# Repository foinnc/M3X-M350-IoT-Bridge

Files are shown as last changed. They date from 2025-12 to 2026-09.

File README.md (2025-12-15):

# 🌉 M3X-M350-IoT-Bridge

**An Open Source IoT Expansion Box designed exclusively for the M350 CNC Controller.**

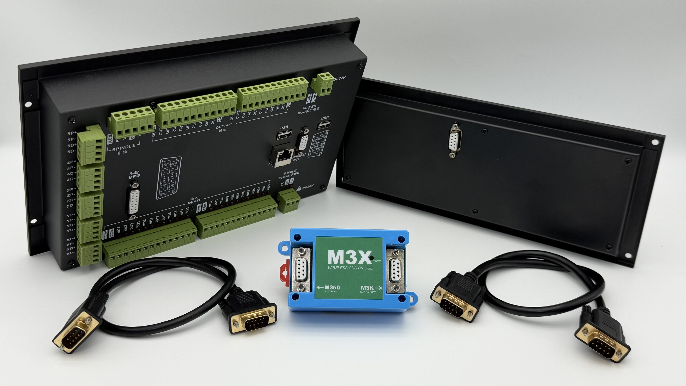
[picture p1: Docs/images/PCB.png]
M3X PCB
 
---

## ✨ 1. Project Overview: Unleash Wireless Imagination

The **M3X-M350-IoT-Bridge** is an open-source hardware project designed to empower the classic M350 CNC controller with modern **IoT (Internet of Things)** capabilities.

By integrating powerful **Wi-Fi** and **Bluetooth** wireless protocols, the M3X box acts as a bridge, allowing various Human-Machine Interfaces (HMI) and wireless terminals to access the M350 system.

**With the M3X, your M350 gains:**
* **Wireless Freedom:** Replace wired limitations with Wi-Fi/Bluetooth control.
* **Smart Connectivity:** Supports standard wireless protocols for flexible development.
* **Expanded Potential:** From simple remote jogging to complex cloud monitoring, unleash the wireless imagination of your CNC system.

### 📷 Product Visualization

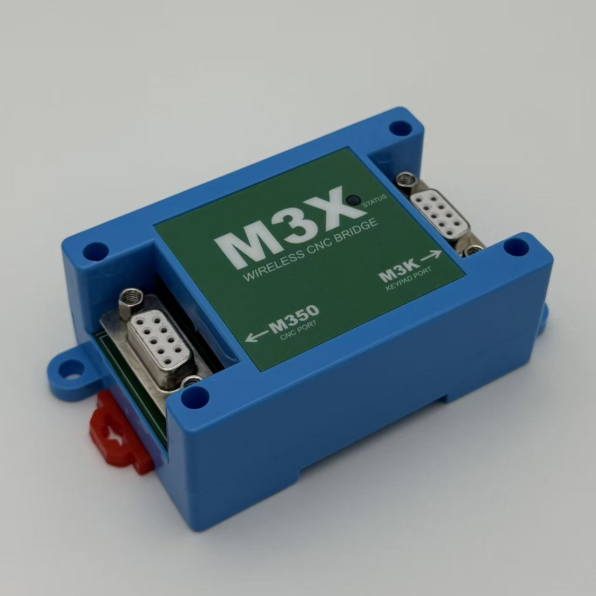
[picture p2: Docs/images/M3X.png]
M3X Project Banner
 

*(Note: The M3X is compact, robust, and designed to sit neatly beside your controller.)*

---

## 🔌 2. Connectivity & Power

We designed the M3X for ultimate simplicity. **Zero soldering, Zero complex wiring.**

* **Connection Method:** Connects via a single **DB9 Male-to-Male Extension Cable**.
* **Plug and Play:** Simply plug one end into the M3X and the other into the M350's serial port.
* **Power Supply:** No external power adapter is needed! The M3X draws 5V power directly from the M350 controller through the DB9 cable.

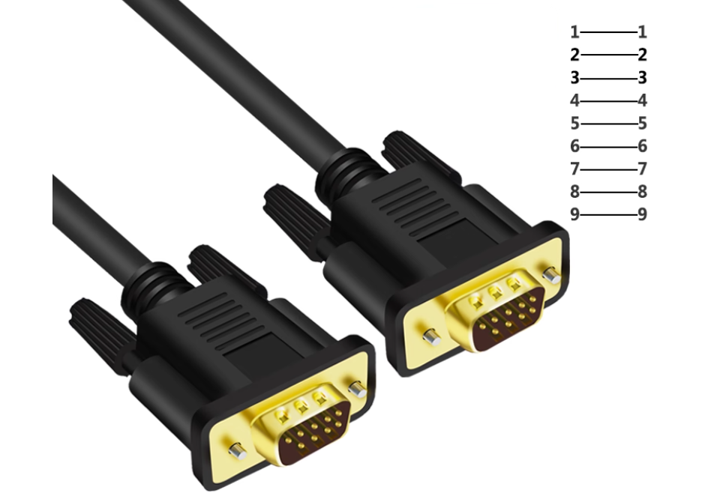
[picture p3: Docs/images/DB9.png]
DB9 Connection Cable
 

---

## 💻 3. Hardware Compatibility

The M3X is compatible with the majority of M350 controllers in the market:

| Hardware Version | Compatibility Status | Note |
| :--- | :--- | :--- |
| **M350 V2** | ✅ **Fully Compatible** | All V2 hardware versions support direct power and data. |
| **M350 V1** | ⚠️ **Partial Support** | Only V1 versions equipped with a **5V output** on the serial port are supported. |

---

## 📱 4. Application Case: Wi-Fi Web Control

The M3X allows you to control the CNC remotely via a web interface.

> **📢 Prerequisite (Important):**
> Before attempting to communicate with the M350, you must flash the firmware into the IoT Box.
>
> Please follow the [**Firmware Flashing Guide**](Docs/Flashing_Guide.md) to flash the `M3X_Web_Control_v1.0.bin` file to your device first.

### How to Use:

1.  **Power On:** Turn on your M350 (and thus the M3X).
2.  **Connect Wi-Fi:** On your Phone, Tablet (iPad/Android), or Laptop, search for the Wi-Fi hotspot.
    * **SSID (Name):** `M3X`
3.  **Open Browser:** Launch any web browser (Chrome, Safari, Edge, etc.) and enter the address:
    * **URL:** `192.168.4.1`

**You now have a wireless CNC control panel right in your hand!**

---

## ⚙️ 5. M350 System Configuration (Critical Setup)

### ⚠️ **CNC Firmware Requirement**
For the M3X to function correctly, your **M350 CNC Controller firmware** must be version **2025-12-11-00 or newer**. Earlier versions may not support the required Modbus communication protocol settings.

**➡️ M350 Firmware Download Link:** [https://github.com/foinnc/M350/releases/](https://github.com/foinnc/M350/releases/) 

---

For the M3X to communicate successfully, you **must** configure the M350 CNC Controller's internal parameters as follows.

**Go to the M350 "Parameters" page and set:**

| Parameter No. | Parameter Name | Setting Value | Description |
| :--- | :---: | :---: | :--- |
| **P279** | **Modbus RTU** | **Slave** | Sets M350 as a Modbus Slave (Server). |
| **P267** | **Serial 2 Baud Rate** | **115200** | Matches the M3X high-speed communication rate. |
| **P296** | **Parity Check** | **Default** | Leave as system default (Usually None/Even). |
| **P297** | **Stop Bits** | **Default** | Leave as system default (Usually 1 bit). |

> ⚠️ **IMPORTANT:** After changing these parameters, you **MUST REBOOT (Restart)** the M350 controller for the changes to take effect.

---

## 🎬 6. Demos & Gallery

See the M3X in action!

### Video Demonstration
[**▶️ Click here to watch the M3X Setup & Demo Video**](https://youtu.be/5DFLAazw6eI)

*(Or use the thumbnail embed method below)*
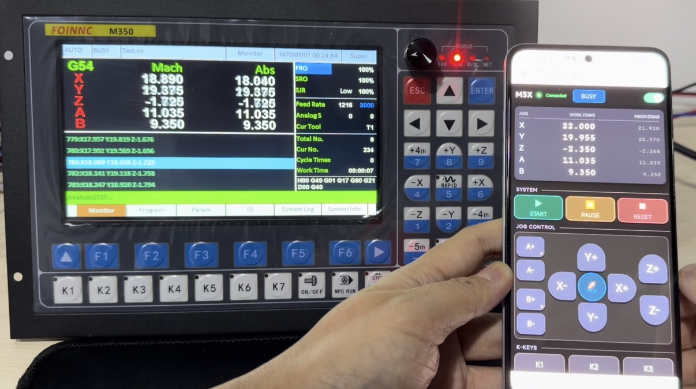
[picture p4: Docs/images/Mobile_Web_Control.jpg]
Video Thumbnail


### Project Gallery
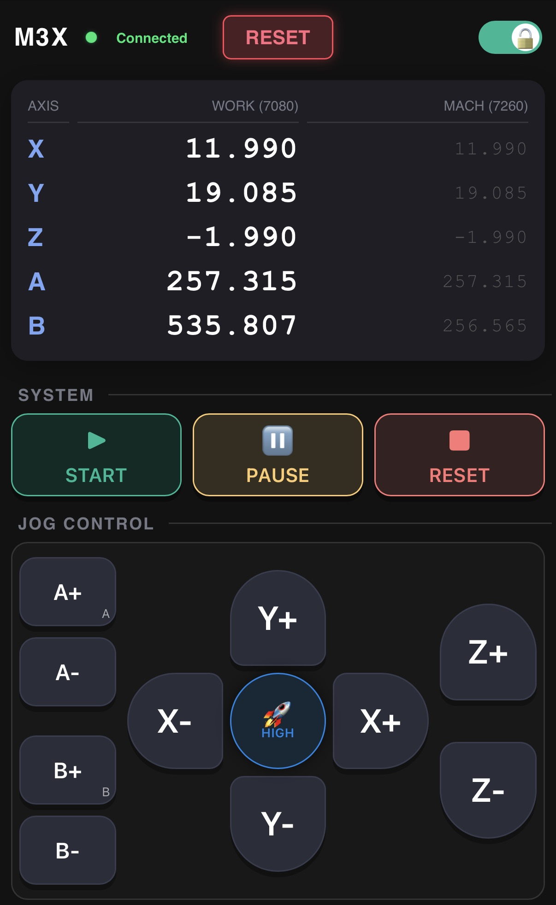
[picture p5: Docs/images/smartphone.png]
Web Control Interface

*(Caption: The responsive web interface on a smartphone)*

M3X Installed
*(Caption: The M3X bridge connected to the M350 CNC controller)*

---

## 📚 Documentation & Resources

* **Flash Firmware:** [Firmware Flashing Guide](Docs/Flashing_Guide.md) - Step-by-step flashing instructions.
* **Hardware Details:** [ESP32-C3 Core Module Introduction](Docs/ESP32_C3_Core_Introduction.md) - Pinouts and specs. 
  > **💡 Note:** The core component, the **ESP32-C3 Super Mini**, can be purchased as a readily available module, eliminating the need for custom PCB design. 
* **Source Code:** Check the `Firmware/` folder for source code examples.
* **Schematics:** Check the `Hardware/` folder for circuit diagrams.

---

_Open Source Project - Use at your own risk and enjoy the freedom of DIY!_

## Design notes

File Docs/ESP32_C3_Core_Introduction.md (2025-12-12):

# ⚡ ESP32-C3 Core Module Introduction

This document provides a detailed overview of the ESP32-C3 core module, including its technical specifications, hardware resources, and critical operating instructions.

---

## ⚙️ 1. Product Specifications

The core module is built around the highly integrated ESP32-C3 chip, offering robust Wi-Fi and Bluetooth capabilities in a compact design.

| Feature | Specification |
| :--- | :--- |
| **Processor** | ESP32-C3, 32-bit RISC-V Single-Core CPU |
| **Frequency** | Up to 160 MHz |
| **Wi-Fi** | 802.11 b/g/n, 2.4 GHz (Station, SoftAP, SoftAP+Station, Promiscuous) |
| **Bluetooth** | Bluetooth 5.0 (BLE) |
| **Low Power** | Deep-sleep current approx. 43 $\mu$A |
| **Memory** | 400 KB SRAM, 384 KB ROM, Built-in 4 MB Flash |
| **Chip Model** | ESP32C3FN4 |
| **Size** | 23 $\times$ 19 mm classic form factor |
| **Design** | Single-sided components, Surface Mount Design (SMD) |
| **Onboard Blue LED** | Connected to **GPIO8** |

---

## 🔌 2. Rich Peripheral Interfaces

The module provides a rich set of I/O and communication interfaces:

* **General Purpose I/O (GPIO):** 11x (PWM capable)
* **Analog Input:** 4x ADC (Analog-to-Digital Converter)
* **Serial Communication:** 2x UART
* **Synchronous Communication:** 1x I2C, 1x SPI

### 2.1 Pinout Diagram

The following diagram illustrates the pin assignment and peripheral mapping for the core module:

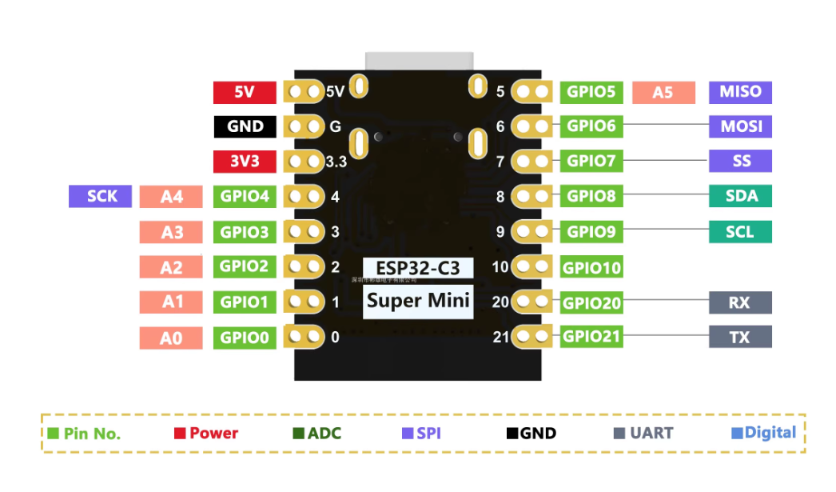
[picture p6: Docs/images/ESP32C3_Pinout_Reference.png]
ESP32-C3 Core Module Pinout Diagram
 

---

## ⚠️ 3. Operational Notes and Instructions

### 3.1 External Power Supply

* If external power is required, connect the **Positive (+)** terminal of the external supply to the **5V** pin, and the **Ground (GND)** terminal to the negative pole.
* **Supported Range:** The module supports a voltage range of **3.3V to 6V**.
* **Crucial Warning:** When connecting an external power supply, **USB power must be disconnected**. USB and external power are mutually exclusive; use only one source to prevent damage.

### 3.2 Entering Download Mode (Flashing)

The chip must be manually set to Download Mode before flashing new firmware (required for each new connection/flashing session).

1.  **Press and Hold** the **BOOT** button on the ESP32-C3 module.
2.  **Press** the **RESET** button.
3.  **Release** the **RESET** button.
4.  **Finally, Release** the **BOOT** button.

The ESP32-C3 should now be in Download Mode. If the port disconnects unexpectedly (sometimes indicated by a port recognition sound), you may need to repeat the sequence.

---

## 💡 4. Schematic Diagram (原理图)

For hardware replication, debugging, and detailed component inspection, please refer to the schematic diagram.

The full schematic is provided in the repository's documentation files:

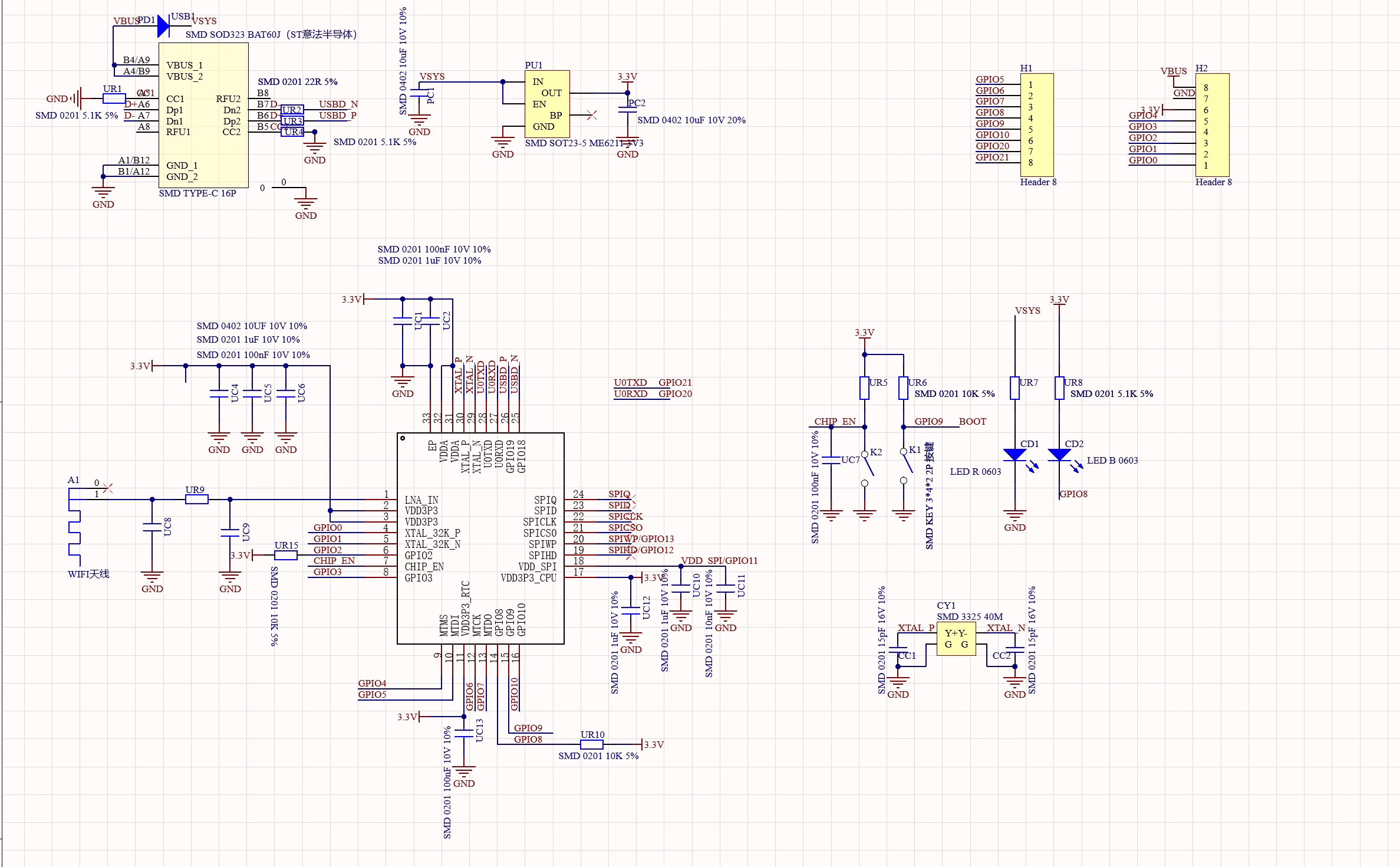
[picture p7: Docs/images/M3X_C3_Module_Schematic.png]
M3X Core Module Schematic Preview


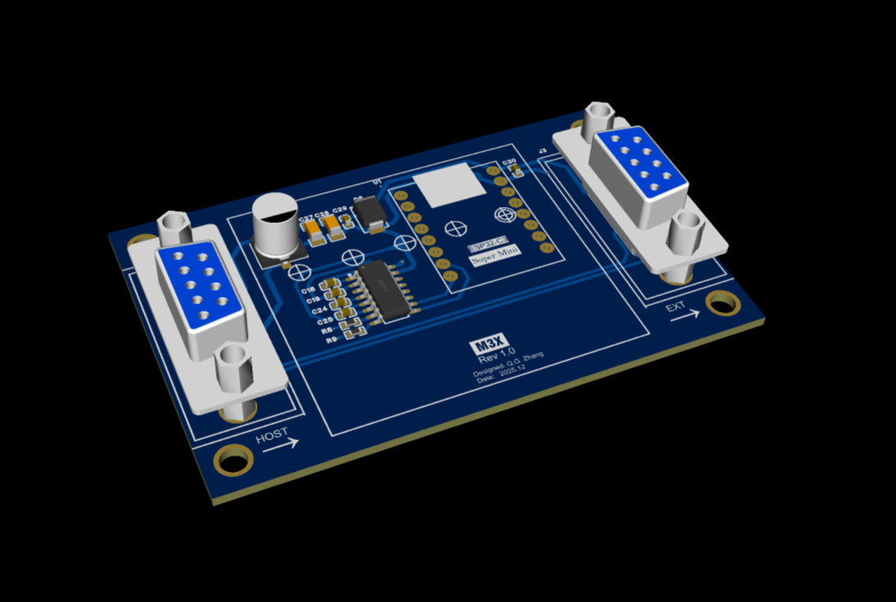
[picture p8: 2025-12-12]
Hardware/PCB_Gerber/3D.png

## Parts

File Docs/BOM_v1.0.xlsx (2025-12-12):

No. | Quantity | Comment | Designator | Footprint | Value | Manufacturer Part | Manufacturer | Supplier Part | Supplier
1 | 6 | 100nF | C18,C19,C24,C25,C29,C30 | C0603 | 100nF | CC0603KRX7R9BB104 | YAGEO(国巨) | C14663 | LCSC
2 | 2 | 22uF | C26,C27 | C1206 | 22uF | CL31A226KPHNNNE | SAMSUNG(三星) | C5672 | LCSC
3 | 1 | 100uF | C28 | CAP-SMD_BD6.3-L6.6-W6.6-LS7.2-FD | 100uF | RVT1C101M0605 | HONOR(荣誉) | C37308 | LCSC
4 | 1 | SMBJ6.5A | D6 | SMB_L4.6-W3.6-LS5.3-RD |  | SMBJ6.5A | MDD(辰达半导体) | C113978 | LCSC
5 | 2 | DS1034-09FUNSi44 | J2,J3 | DSUB-TH_2-5747706-0 |  | DS1034-09FUNSi44 | CONNFLY | C77831 | LCSC
6 | 2 | 20Ω | R8,R9 | R0603 | 20Ω | 0603WAF200JT5E | UNI-ROYAL(厚声) | C22950 | LCSC
7 | 1 | ESP32_C3mini | U1 | ESP32_C3_mini
8 | 1 | MAX232ACSE | U4 | SOP-16_L10.0-W3.9-P1.27-LS6.0-BL

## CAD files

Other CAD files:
Hardware/Case_Drawings/1152(3-59-2).dwg

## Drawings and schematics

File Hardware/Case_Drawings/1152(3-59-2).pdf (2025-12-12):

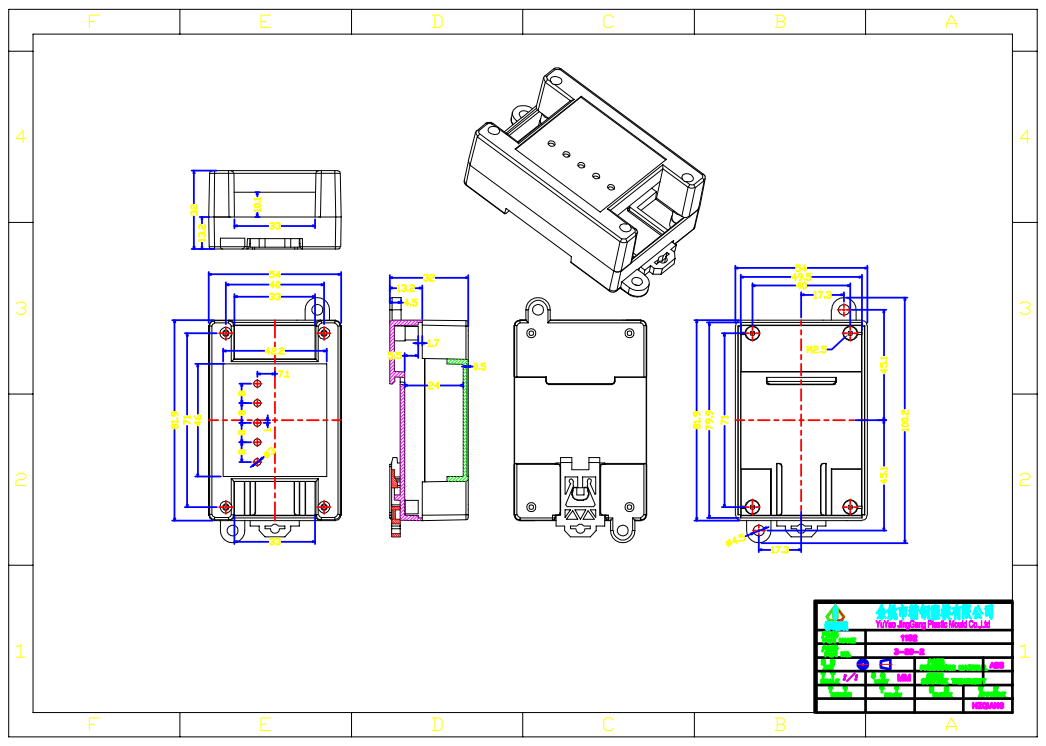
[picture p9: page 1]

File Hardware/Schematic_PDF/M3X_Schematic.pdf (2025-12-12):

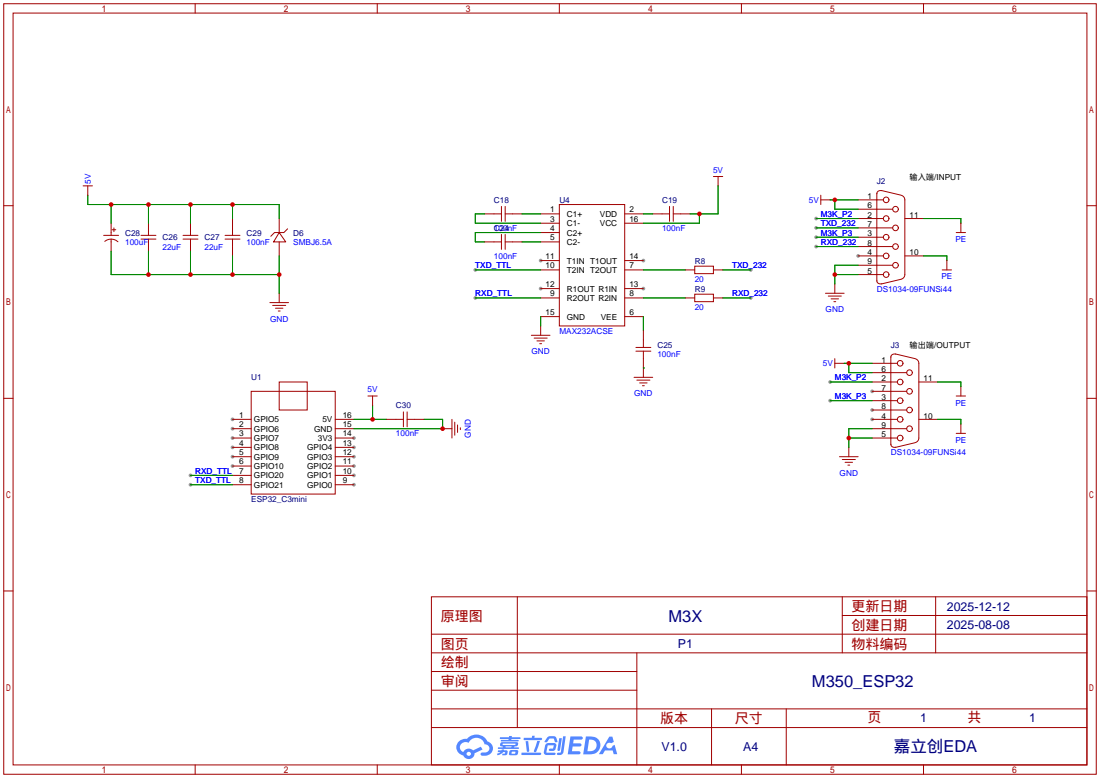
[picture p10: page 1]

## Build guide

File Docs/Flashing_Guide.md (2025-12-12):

# 💻 ESP32-C3 Firmware Flashing Guide (Beginner's Edition)

This guide provides **step-by-step instructions** for flashing the M3X control firmware onto your ESP32-C3 core module using the simple, browser-based **Adafruit WebSerial ESPTool**.

---

## ⚙️ 1. Preparation Checklist

Ensure you have all the necessary components and files before proceeding:

1.  **Core Module:** An **ESP32-C3 Super Mini** core board.
2.  **Cable:** A reliable USB Type-C data cable.
3.  **Firmware File:** The specific `.bin` file you need to flash.
    * **File Location in this Repository:** `Firmware\01_Web_Touch_Console\M3X_Web_Control_v1.0.bin`
    * **Function:** This firmware allows you to control the M350 via a web interface or mobile phone using the core board's Wi-Fi hotspot.
4.  **Browser Tool:** The online flashing tool.
    * **Tool URL:** [https://adafruit.github.io/Adafruit_WebSerial_ESPTool/](https://adafruit.github.io/Adafruit_WebSerial_ESPTool/)
    * **Requirement:** Use a Chromium-based browser (Google Chrome or Microsoft Edge).

---

## ⚠️ 2. Essential Setup: Enter Download Mode

Before your computer can communicate with the ESP32-C3 for flashing, the module must be placed into a special **Download Mode** (also called Bootloader Mode).

### Procedure:

1.  **Connect the Cable:** Plug the USB Type-C cable into the module and your computer.
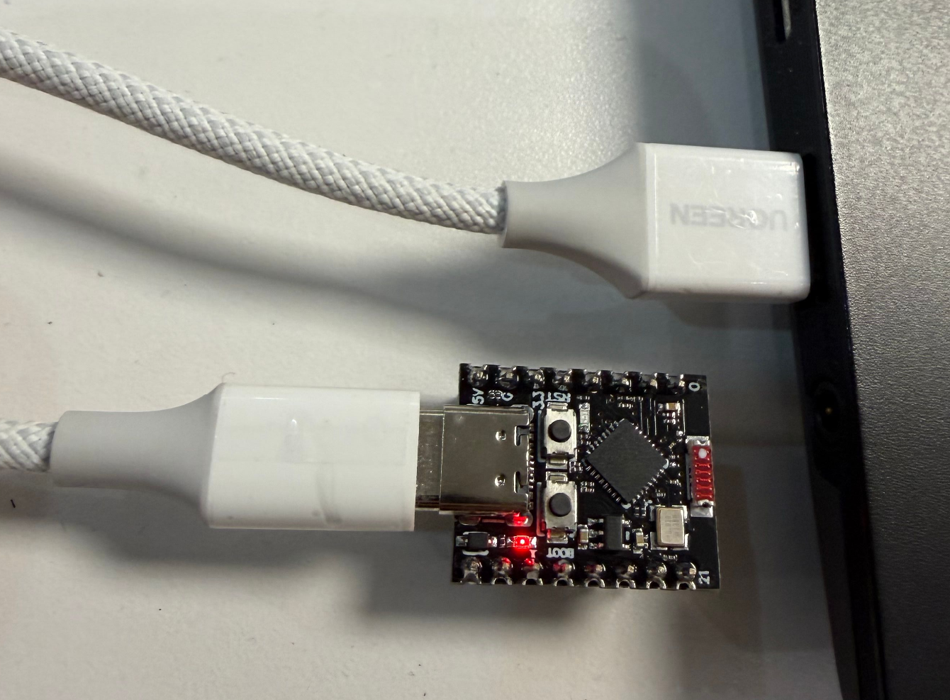
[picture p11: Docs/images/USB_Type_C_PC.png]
USB_Type_C_PC
 

2.  **Locate Buttons:** Identify the **BOOT** button (usually near the USB port) and the **RESET** button.
3.  **Press BOOT:** **Press and HOLD DOWN** the **BOOT** button (Do not release yet!).
4.  **Press RESET:** While holding BOOT, briefly **PRESS and RELEASE** the **RESET** button.
5.  **Release BOOT:** Wait for about one second, then **RELEASE** the **BOOT** button.

> **Crucial Note:** This manual procedure is required **every time** you start the flashing process. If you encounter errors later, repeat these steps immediately before reconnecting.

---

## 🚀 3. Step-by-Step Flashing Procedure

Follow these steps precisely to successfully burn the firmware:

### Step A: Set Baud Rate and Connect the Device

1.  Open the **Adafruit WebSerial ESPTool** URL in your browser: [https://adafruit.github.io/Adafruit_WebSerial_ESPTool/](https://adafruit.github.io/Adafruit_WebSerial_ESPTool/)
2.  **Set Baud Rate:** Locate the baud rate selection dropdown menu (usually near the top right corner). **Select `115200`**.
    > **Note on Baud Rate:** While the tool might support faster rates, **115200** is the standard, most reliable rate for the initial connection and stability across different computer systems.
3.  Locate the large **CONNECT** button (usually blue) on the page and click it.
4.  A pop-up window will appear, listing available serial ports.
5.  **Select Port:** Choose the port that corresponds to your ESP32-C3 (e.g., 'USB to UART').
6.  **Confirm Connection:** Click **Connect**. The button should change to **DISCONNECT** if successful.
    * *(If the tool fails to connect, ensure the module is in Download Mode (Section 2.1).)*

### Step B: Load the Firmware File

1.  After connecting, look for the **"Files to flash"** section on the page.
2.  **Set Start Address:** Ensure the address field is set to **`0x0`** (zero).
    * **Start Address Value:** `0`
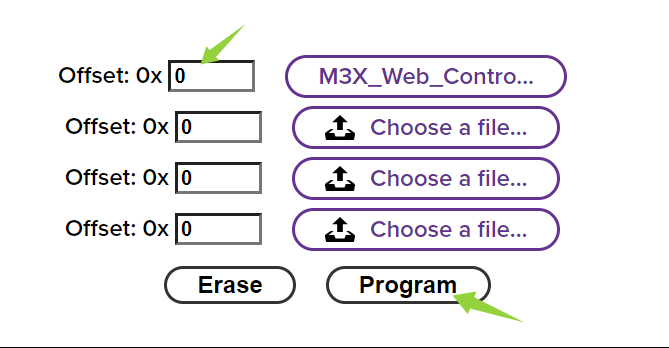
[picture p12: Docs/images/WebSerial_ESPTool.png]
 
    
3.  **Select File:** Click the **Browse** button next to the address field.
4.  A file explorer window will open. Navigate to the firmware file **`M3X_Web_Control_v1.0.bin`** in your local clone of the repository.

### Step C: Execute Flashing

1.  Once the file is selected and the address is confirmed, click the **Program** button.
2.  **Monitor Progress:** The tool will automatically start erasing the old firmware and writing the new `.bin` file. Watch the progress bar in the log window.
3.  **Wait for Success:** The process is complete when you see a bright green **"Success!"** message in the log area. **Do not disconnect the cable until this message appears.**

### Step D: Disconnect and Run

1.  Click the **DISCONNECT** button on the web tool interface.
2.  **Run Firmware:** Briefly press the **RESET** button on the ESP32-C3 core board.

The module will exit Download Mode and immediately begin running the new `M3X_Web_Control_v1.0.bin` firmware. Your core module is now ready to broadcast its Wi-Fi hotspot for M350 control.

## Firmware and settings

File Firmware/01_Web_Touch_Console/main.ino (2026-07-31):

#include <WiFi.h>
#include <WebServer.h>
#include <WebSocketsServer.h>
// *** 必须先安装 ModbusMaster 库 (D. G. Lunn 版本) ***
#include <ModbusMaster.h> 

// --- 指示灯定义 ---
#define LED_PIN 8  // GPIO8，低电平点亮

const char* ssid = "M3X";
const char* password = "12345678";

// --- 硬件定义 ---
const int RXD1 = 20;
const int TXD1 = 21;

// --- Modbus 设置 ---
const uint8_t SLAVE_ID = 0x01; 
const uint16_t START_REG_WRITE = 6908; 
const uint16_t REG_READ_WORK = 7080; 
const uint16_t REG_READ_MACH = 7260; 
const uint16_t REG_READ_STAT = 10002; 

ModbusMaster node; 
unsigned long lastReadTime = 0;
const long readInterval = 100; 

WebServer server(80);
WebSocketsServer webSocket = WebSocketsServer(81); 

// LED 状态变量
bool led_state = false; 

// 闪烁 LED 函数
void blinkLED() {
    led_state = !led_state;
    digitalWrite(LED_PIN, led_state ? LOW : HIGH);
}

// *********************************************************************************
// ********* HTML 界面 (保持不变) *********
// *********************************************************************************
const char MAIN_page[] PROGMEM = R"HTML(
<!DOCTYPE html>
<html>
<head>
<meta charset="UTF-8">
<meta name="viewport" content="width=device-width, initial-scale=1, user-scalable=no, maximum-scale=1, user-scalable=0">
<title>M3X 5-Axis Pro</title>
<style>
* { box-sizing: border-box; }
:root {
    --bg-color: #121212; --card-bg: #1e1e24; --btn-bg: #2a2d3a; --btn-border: #383c4d;
    --text-main: #ffffff; --text-sub: #757985; --text-accent: #7aa5f5;
    --btn-start: #00b894; --btn-pause: #fdcb6e; --btn-reset: #ff7675; 
    --btn-speed: #0984e3; --btn-fkey:  #6c5ce7; 
}
body { 
    font-family: 'Roboto', sans-serif; background-color: var(--bg-color); color: var(--text-main);
    margin: 0; padding: 8px; display: flex; flex-direction: column; align-items: center;
    min-height: 100vh; touch-action: manipulation; -webkit-user-select: none; user-select: none;
}
@keyframes breathing {
    0% { box-shadow: 0 0 2px rgba(0, 230, 118, 0.3); transform: scale(1); }
    50% { box-shadow: 0 0 8px rgba(0, 230, 118, 0.8); transform: scale(1.2); }
    100% { box-shadow: 0 0 2px rgba(0, 230, 118, 0.3); transform: scale(1); }
}
.header-panel {
    width: 100%; max-width: 450px; display: grid; 
    grid-template-columns: 1fr auto 1fr; 
    align-items: center; gap: 5px; margin-bottom: 10px; padding: 5px 2px;
}
.left-group { display: flex; align-items: center; gap: 12px; justify-self: start; }
h2 { margin: 0; font-size: 18px; font-weight: 900; color: var(--text-main); letter-spacing: 1px; line-height: 1; }
.conn-wrapper { display: flex; align-items: center; gap: 6px; }
.dot { width: 8px; height: 8px; border-radius: 50%; background: #555; transition: all 0.3s; }
.dot.ok { background: #00e676; animation: breathing 2s infinite ease-in-out; } 
#conn-text { font-size: 10px; color: #666; font-weight: bold; padding-top: 1px;}
.sys-status {
    justify-self: center; font-size: 14px; font-weight: bold;
    color: #fff; background: #333; padding: 6px 12px; border-radius: 6px;
    min-width: 80px; text-align: center; white-space: nowrap;
    border: 1px solid #444; transition: all 0.3s;
}
.st-idle { background-color: rgba(0, 184, 148, 0.2); color: #00b894; border-color: #00b894; }
.st-run  { background-color: rgba(9, 132, 227, 0.2); color: #74b9ff; border-color: #0984e3; }
.st-reset { background-color: rgba(255, 71, 87, 0.25); color: #ff6b81; border-color: #ff4757; box-shadow: 0 0 8px rgba(255, 71, 87, 0.4); }
.st-off  { background-color: #2d3436; color: #636e72; border-color: #636e72; }
.lock-wrapper { justify-self: end; display: flex; align-items: center; }
.switch { position: relative; display: inline-block; width: 46px; height: 24px; }
.switch input { opacity: 0; width: 0; height: 0; }
.slider { position: absolute; cursor: pointer; top: 0; left: 0; right: 0; bottom: 0; background-color: #444; transition: .4s; border-radius: 34px; border: 1px solid #666; }
.slider:before { position: absolute; content: "🔒"; font-size: 12px; display:flex; justify-content:center; align-items:center; height: 20px; width: 20px; left: 1px; bottom: 1px; background-color: #bbb; transition: .4s; border-radius: 50%; color: #333;}
input:checked + .slider { background-color: var(--btn-start); border-color: var(--btn-start); }
input:checked + .slider:before { transform: translateX(22px); content: "🔓"; background-color: #fff; }
.ui-disabled { opacity: 0.3; pointer-events: none; filter: grayscale(0.8); transition: opacity 0.3s; }
.dro-panel {
    background-color: var(--card-bg); border-radius: 12px; padding: 12px; width: 100%; max-width: 450px;
    box-shadow: 0 4px 20px rgba(0,0,0,0.3); display: grid; grid-template-columns: 30px 1fr 1fr; gap: 6px;
    align-items: center; margin-bottom: 5px;
}
.dro-header { color: var(--text-sub); font-size: 10px; text-align: right; padding-bottom: 5px; border-bottom: 1px solid rgba(255,255,255,0.1); }
.axis-name { font-size: 18px; font-weight: 900; color: var(--text-accent); }
.coord-val { font-family: 'Courier New', monospace; text-align: right; letter-spacing: 0.5px; }
.work-pos { font-size: 22px; font-weight: bold; color: var(--text-main); }
.mach-pos { font-size: 14px; color: #555; }
.controls-wrapper { width: 100%; max-width: 450px; display: flex; flex-direction: column; }
.section-title {
    width: 100%; color: var(--text-sub); font-size: 12px; font-weight: bold; letter-spacing: 1px;
    margin: 12px 0 6px 5px; text-transform: uppercase; display: flex; align-items: center;
}
.section-title::after { content: ''; flex: 1; height: 1px; background: #333; margin-left: 10px; }
button {
    background-color: var(--btn-bg); color: var(--text-main); border: 1px solid var(--btn-border);
    border-radius: 12px; font-weight: 600; cursor: pointer; box-shadow: 0 4px 0 rgba(0,0,0,0.3);
    transition: transform 0.05s, box-shadow 0.05s; -webkit-tap-highlight-color: transparent;
    display: flex; justify-content: center; align-items: center; position: relative; overflow: hidden;
}
button:active, button.active { transform: translateY(3px); box-shadow: 0 1px 0 rgba(0,0,0,0.3); filter: brightness(1.2); }
.sys-grid { display: grid; grid-template-columns: 1fr 1fr 1fr; gap: 8px; }
.btn-sys { height: 60px; font-size: 14px; flex-direction: column; gap: 4px; }
.btn-sys i { font-size: 20px; font-style: normal; }
.btn-start { background-color: rgba(0, 184, 148, 0.15); border-color: var(--btn-start); color: var(--btn-start); }
.btn-pause { background-color: rgba(253, 203, 110, 0.15); border-color: var(--btn-pause); color: var(--btn-pause); }
.btn-reset { background-color: rgba(255, 118, 117, 0.15); border-color: var(--btn-reset); color: var(--btn-reset); }
.jog-container {
    background-color: #181818; border-radius: 12px; padding: 10px 5px; border: 1px solid #333;
    display: grid; grid-template-columns: 0.8fr 2.5fr 0.8fr; gap: 8px; align-items: center;
}
.jog-btn-base { height: 60px; width: 100%; font-size: 20px; position: relative; border-radius: 12px; }
.col-ab { display: flex; flex-direction: column; gap: 8px; height: 100%; justify-content: center; }
.btn-ab { height: 50px; font-size: 16px; }
.btn-ab::after { content: attr(data-label); position: absolute; bottom: 2px; right: 3px; font-size: 9px; opacity: 0.6; font-weight: normal; }
.col-z { display: flex; flex-direction: column; gap: 30px; height: 100%; justify-content: center; }
.btn-z-up { height: 70px; font-size: 24px; border-radius: 50% 50% 12px 12px; }
.btn-z-down { height: 70px; font-size: 24px; border-radius: 12px 12px 50% 50%; }
.xy-pad {
    display: grid; grid-template-columns: 1fr 1fr 1fr; grid-template-rows: 1fr 1fr 1fr;
    gap: 5px; width: 100%; aspect-ratio: 1/1;
}
.btn-center { 
    grid-column: 2; grid-row: 2; z-index: 2; border-radius: 50%; height: 100%;
    background-color: rgba(9, 132, 227, 0.15); border-color: var(--btn-speed); color: var(--btn-speed);
    box-shadow: 0 0 10px rgba(0,0,0,0.5); flex-direction: column; font-size: 10px;
}
.speed-icon { font-size: 16px; margin-bottom: -2px; }
.btn-dir { width: 100%; height: 100%; font-size: 24px; }
.btn-y-plus { grid-column: 2; grid-row: 1; border-radius: 50% 50% 10px 10px; }
.btn-y-minus { grid-column: 2; grid-row: 3; border-radius: 10px 10px 50% 50%; }
.btn-x-minus { grid-column: 1; grid-row: 2; border-radius: 50% 10px 10px 50%; }
.btn-x-plus { grid-column: 3; grid-row: 2; border-radius: 10px 50% 50% 10px; }
.fkey-grid { display: grid; grid-template-columns: 1fr 1fr 1fr; gap: 10px; }
.btn-fkey { height: 50px; font-size: 16px; font-weight: bold; color: #ccc; border-color: #555; background: #25252b; }
.btn-fkey:active { background: var(--btn-fkey); color: #fff; border-color: var(--btn-fkey); }
#footer { margin-top: 20px; font-size: 12px; color: var(--text-sub); display: flex; align-items: center; justify-content: center;}
.dot { width: 8px; height: 8px; border-radius: 50%; background: #444; margin-right: 8px; }
.dot.ok { background: #00e676; box-shadow: 0 0 6px #00e676; }
</style>
</head>
<body>
<div class="header-panel">
    <div class="left-group">
        <h2>M3X</h2>
        <div class="conn-wrapper">
            <span id="conn-dot" class="dot"></span>
            <span id="conn-text">Connecting...</span>
        </div>
    </div>
    <div id="sys-state" class="sys-status">OFFLINE</div>
    <div class="lock-wrapper">
        <label class="switch"><input type="checkbox" id="safety-switch" onchange="toggleLock()"><span class="slider"></span></label>
    </div>
</div>
<div class="dro-panel">
    <div class="dro-header" style="text-align:left">AXIS</div><div class="dro-header">WORK (7080)</div><div class="dro-header">MACH (7260)</div>
    <div class="axis-name">X</div><div id="w-X" class="coord-val work-pos">0.000</div><div id="m-X" class="coord-val mach-pos">0.000</div>
    <div class="axis-name">Y</div><div id="w-Y" class="coord-val work-pos">0.000</div><div id="m-Y" class="coord-val mach-pos">0.000</div>
    <div class="axis-name">Z</div><div id="w-Z" class="coord-val work-pos">0.000</div><div id="m-Z" class="coord-val mach-pos">0.000</div>
    <div class="axis-name">A</div><div id="w-A" class="coord-val work-pos">0.000</div><div id="m-A" class="coord-val mach-pos">0.000</div>
    <div class="axis-name">B</div><div id="w-B" class="coord-val work-pos">0.000</div><div id="m-B" class="coord-val mach-pos">0.000</div>
</div>
<div id="ctrl-container" class="controls-wrapper ui-disabled">
    <div class="section-title">System</div>
    <div class="sys-grid">
        <button class="btn-sys btn-start" onclick="sendCmd('START01')"><i>▶</i>START</button>
        <button class="btn-sys btn-pause" onclick="sendCmd('PAUSE01')"><i>⏸</i>PAUSE</button>
        <button class="btn-sys btn-reset" onclick="sendCmd('RESET01')"><i>■</i>RESET</button>
    </div>
    <div class="section-title">Jog Control</div>
    <div class="jog-container">
        <div class="col-ab">
            <button class="jog-btn-base btn-ab" data-axis="A" data-dir="+" data-label="A">A+</button>
            <button class="jog-btn-base btn-ab" data-axis="A" data-dir="-">A-</button>
            <div style="height:5px"></div>
            <button class="jog-btn-base btn-ab" data-axis="B" data-dir="+" data-label="B">B+</button>
            <button class="jog-btn-base btn-ab" data-axis="B" data-dir="-">B-</button>
        </div>
        <div class="xy-pad">
            <button class="jog-btn-base btn-dir btn-y-plus" data-axis="Y" data-dir="+">Y+</button>
            <button class="jog-btn-base btn-dir btn-x-minus" data-axis="X" data-dir="-">X-</button>
            <button class="jog-btn-base btn-center" id="btn-speed"><span id="speed-icon" class="speed-icon">🚀</span><span id="speed-txt" style="font-size:9px">HIGH</span></button>
            <button class="jog-btn-base btn-dir btn-x-plus" data-axis="X" data-dir="+">X+</button>
            <button class="jog-btn-base btn-dir btn-y-minus" data-axis="Y" data-dir="-">Y-</button>
        </div>
        <div class="col-z">
            <button class="jog-btn-base btn-z-up" data-axis="Z" data-dir="+">Z+</button>
            <button class="jog-btn-base btn-z-down" data-axis="Z" data-dir="-">Z-</button>
        </div>
    </div>
    <div class="section-title">K-Keys</div>
    <div class="fkey-grid">
        <button class="btn-fkey" onclick="sendCmd('F101')">K1</button>
        <button class="btn-fkey" onclick="sendCmd('F201')">K2</button>
        <button class="btn-fkey" onclick="sendCmd('F301')">K3</button>
        <button class="btn-fkey" onclick="sendCmd('F401')">K4</button>
        <button class="btn-fkey" onclick="sendCmd('F501')">K5</button>
        <button class="btn-fkey" onclick="sendCmd('F601')">K6</button>
    </div>
</div>
<div id="footer"><span id="conn-dot" class="dot"></span><span id="conn-text">Connecting...</span></div>
<script>
var socket; var pressTimer=null; var activeBtn=null; var isUnlocked=false; var isHighSpeed=true;
const LONG_PRESS_MS=300; 
function toggleLock(){ isUnlocked=document.getElementById('safety-switch').checked; var d=document.getElementById('ctrl-container'); if(isUnlocked) d.classList.remove('ui-disabled'); else { d.classList.add('ui-disabled'); if(activeBtn) endPress(null); } }
document.getElementById('btn-speed').addEventListener('click', function() {
    if(!isUnlocked) return;
    isHighSpeed = !isHighSpeed;
    var t=document.getElementById('speed-txt'), i=document.getElementById('speed-icon');
    if(isHighSpeed) { t.innerText="HIGH"; i.innerText="🚀"; this.style.color="#0984e3"; this.style.borderColor="#0984e3"; }
    else { t.innerText="LOW"; i.innerText="🐢"; this.style.color="#ccc"; this.style.borderColor="#666"; }
    sendCmd(isHighSpeed ? "HF01" : "LF01"); 
});
function updateConn(s,k){ 
    var txt = document.getElementById('conn-text');
    var dot = document.getElementById('conn-dot');
    txt.innerText = s;
    if(k) { dot.classList.add('ok'); txt.style.color = "#00e676"; } else { dot.classList.remove('ok'); txt.style.color = "#777"; }
}
function initWebSocket() {
  socket = new WebSocket("ws://" + location.hostname + ":81/");
  socket.onopen = function() { updateConn("Connected", true); };
  socket.onclose = function() { updateConn("Disconnected", false); setTimeout(initWebSocket, 1000); };
  socket.onerror = function() { updateConn("Error", false); };
  socket.onmessage = function(e) {
      var msg = e.data; 
      if (msg.startsWith("POS:")) {
          var vals = msg.substring(4).split(",");
          if(vals.length >= 11) {
              document.getElementById('w-X').innerText = vals[0]; document.getElementById('m-X').innerText = vals[5];
              document.getElementById('w-Y').innerText = vals[1]; document.getElementById('m-Y').innerText = vals[6];
              document.getElementById('w-Z').innerText = vals[2]; document.getElementById('m-Z').innerText = vals[7];
              document.getElementById('w-A').innerText = vals[3]; document.getElementById('m-A').innerText = vals[8];
              document.getElementById('w-B').innerText = vals[4]; document.getElementById('m-B').innerText = vals[9];
              var s = vals[10];
              var st = document.getElementById('sys-state');
              st.className = "sys-status"; 
              if(s=="0") { st.innerText="IDLE"; st.classList.add("st-idle"); }
              else if(s=="1") { st.innerText="BUSY"; st.classList.add("st-run"); }
              else if(s=="2") { st.innerText="RESET"; st.classList.add("st-reset"); }
              else { st.innerText="CODE:"+s; st.classList.add("st-off"); }
          }
      }
  };
}
function sendCmd(cmd) { if(!isUnlocked) return; if(socket && socket.readyState===WebSocket.OPEN) socket.send(cmd); }
function startPress(e) {
    if(!isUnlocked) return; 
    if(e.cancelable && !e.target.matches('button')) return;
    if(e.cancelable && e.type === 'touchstart') e.preventDefault(); 
    if(activeBtn) return; var btn = e.target.closest('button'); if(!btn) return;
    if(btn.getAttribute('onclick') || btn.id==='btn-speed') return;
    activeBtn = btn; activeBtn.classList.add('active');
    var axis=btn.getAttribute('data-axis'), dir=btn.getAttribute('data-dir');
    if(axis && dir) {
        sendCmd(axis + dir + "01"); 
        pressTimer = setTimeout(function(){ if(activeBtn) sendCmd(axis+dir+"02"); }, LONG_PRESS_MS);
    } else if (btn.innerHTML.startsWith("F") || btn.classList.contains('btn-sys')) {
        if(btn.onclick) return;
        var txt = btn.innerText.trim();
        if(txt.includes("START")) sendCmd("START01");
        else if(txt.includes("PAUSE")) sendCmd("PAUSE01");
        else if(txt.includes("RESET")) sendCmd("RESET01");
        else sendCmd(txt + "01"); 
    }
}
function endPress(e) {
    if(e && e.cancelable && e.type==='touchend') e.preventDefault();
    if(!activeBtn) return; 
    if(pressTimer) { clearTimeout(pressTimer); pressTimer=null; }
    var axis=activeBtn.getAttribute('data-axis'), dir=activeBtn.getAttribute('data-dir');
    if(axis && dir) sendCmd(axis + dir + "00"); 
    activeBtn.classList.remove('active'); activeBtn.blur(); activeBtn=null;
}
window.onload = function() {
    initWebSocket(); toggleLock();
    var btns = document.querySelectorAll('button');
    btns.forEach(function(btn) {
        if(btn.getAttribute('onclick') || btn.id==='btn-speed') return;
        btn.addEventListener('touchstart', startPress, {passive:false}); btn.addEventListener('touchend', endPress, {passive:false});
        btn.addEventListener('mousedown', startPress); btn.addEventListener('mouseup', endPress); btn.addEventListener('mouseleave', endPress); 
    });
};
</script>
</body>
</html>
)HTML";

// =========================================================================
// ========================= C++ 逻辑部分 ==================================
// =========================================================================

// --- 键值映射表 ---
const uint16_t KeyCodeMap(const String& cmd) {
  if (cmd == "X+") return 0x015e; 
  if (cmd == "X-") return 0x015f; 
  if (cmd == "Y+") return 0x0160; 
  if (cmd == "Y-") return 0x0161; 
  if (cmd == "Z+") return 0x0162; 
  if (cmd == "Z-") return 0x0163; 
  if (cmd == "A+") return 0x0164; 
  if (cmd == "A-") return 0x0165; 
  if (cmd == "B+") return 0x0109; 
  if (cmd == "B-") return 0x0166; 

  if (cmd == "START") return 0x0148;
  if (cmd == "PAUSE") return 0x0149;
  if (cmd == "RESET") return 0x0147;

  if (cmd == "HF") return 0x0184; 
  if (cmd == "LF") return 0x0184;

  if (cmd == "F1") return 0x0600;
  if (cmd == "F2") return 0x0601;
  if (cmd == "F3") return 0x0602;
  if (cmd == "F4") return 0x0603;
  if (cmd == "F5") return 0x0604;
  if (cmd == "F6") return 0x0605;

  return 0x0000; 
}

// ------------------------------------------------
// --- 写入 Modbus 0x10 函数 (按键发送) ---
// ------------------------------------------------
void sendModbusCommand(uint16_t keyCode, uint16_t actionState) {
    uint8_t result;
    node.clearTransmitBuffer();
    
    uint32_t combinedInt = ((uint32_t)actionState << 16) | keyCode;
    float floatVal = (float)combinedInt;

    union {
        float f;
        uint32_t i;
    } data;
    data.f = floatVal;

    uint16_t lowWord = (uint16_t)(data.i & 0xFFFF);        
    uint16_t highWord = (uint16_t)((data.i >> 16) & 0xFFFF); 

    node.setTransmitBuffer(0, lowWord); 
    node.setTransmitBuffer(1, highWord);     
    
    result = node.writeMultipleRegisters(START_REG_WRITE, 2); 
    
    // 如果通讯成功，触发闪烁
    if (result == node.ku8MBSuccess) blinkLED();
}

// ------------------------------------------------
// --- 读取 Modbus 0x03 函数 (CDAB 顺序) ---
// ------------------------------------------------
void readCncStatus() {
    uint8_t result;
    String msg = "POS:";
    bool success_flag = false;

    // 1. 读取工件坐标 (10个寄存器)
    result = node.readHoldingRegisters(REG_READ_WORK, 10);
    if (result == node.ku8MBSuccess) {
        success_flag = true;
        for (int i = 0; i < 5; i++) {
            uint16_t r1 = node.getResponseBuffer(i * 2);
            uint16_t r2 = node.getResponseBuffer(i * 2 + 1);
            union { uint32_t i; float f; } data;
            data.i = ((uint32_t)r2 << 16) | r1; 
            msg += String(data.f, 3) + ",";
        }
    } else {
        msg += "ERR,ERR,ERR,ERR,ERR,";
    }

    // 2. 读取机械坐标
    result = node.readHoldingRegisters(REG_READ_MACH, 10);
    if (result == node.ku8MBSuccess) {
        success_flag = true;
        for (int i = 0; i < 5; i++) {
            uint16_t r1 = node.getResponseBuffer(i * 2);
            uint16_t r2 = node.getResponseBuffer(i * 2 + 1);
            union { uint32_t i; float f; } data;
            data.i = ((uint32_t)r2 << 16) | r1; 
            msg += String(data.f, 3) + ",";
        }
    } else {
        msg += "ERR,ERR,ERR,ERR,ERR,";
    }

    // 3. 读取 IDLE 状态
    result = node.readHoldingRegisters(REG_READ_STAT, 2);
    if (result == node.ku8MBSuccess) {
        success_flag = true;
        uint16_t r1 = node.getResponseBuffer(0);
        uint16_t r2 = node.getResponseBuffer(1);
        union { uint32_t i; float f; } data;
        data.i = ((uint32_t)r2 << 16) | r1; 
        msg += String((int)data.f); 
    } else {
        msg += "99";
    }

    // 只要读取成功，就触发闪烁
    if(success_flag) blinkLED();

    webSocket.broadcastTXT(msg);
}

void handleRoot() {
    server.send(200, "text/html; charset=UTF-8", MAIN_page);
}
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
void loop() {
  server.handleClient();
  webSocket.loop(); 

  if (millis() - lastReadTime >= readInterval) {
    readCncStatus();
    lastReadTime = millis();
  }
}

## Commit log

2025-12-12 feat: Initial stable release of M3X bridge
    First stable release containing all necessary files for hardware replication and firmware installation. Files included: * Firmware/01_Web_Touch_Console/M3X_Web_Control_v1.0.bin (Pre-compiled firmware) * Docs/BOM_v1.0.xlsx & Docs/ESP32_C3_Core_Introduction.md * Docs/Flashing_Guide.md (Instructions for burning the BIN file) * Hardware/PCB_Gerber/Gerber_M3X_Rev1_0.zip (For PCB manufacturing) * Hardware/Case_Drawings/1152(3-59-2).dwg & .pdf (2D case drawings)
    [1152(3-59-2).dwg, BOM_v1.0.xlsx]
2025-12-12 docs: Refine ESP32-C3 documentation and add pinout diagram
    Completed the comprehensive English version of the core module documentation, including detailed specifications, power supply warnings, and flashing instructions. Also added the corresponding pinout 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
2025-12-12 docs: Added comprehensive flashing guide for ESP32-C3 using WebSerial tool
    This new document (Firmware_Flashing_Guide.md) includes step-by-step instructions, baud rate setting, and required image assets for the M3X control firmware.
2025-12-12 docs: Refined resources section, noting ESP32-C3 Super Mini is available as a ready-made module.
